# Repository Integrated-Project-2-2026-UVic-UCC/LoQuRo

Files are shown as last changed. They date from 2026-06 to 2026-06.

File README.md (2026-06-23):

<div align="center">
  
  <h1>LoQuRo</h1>
  <p><b>A fully custom-designed, AI-controlled quadrupedal robot built for under €300.</b><br>
  <i>Proof that autonomous legged locomotion doesn't require a six-figure budget.</i></p>

  
  
  
  
</div>

## Repository Structure

The architecture is cleanly separated into distinct, highly documented modules:

* **[Control & AI](https://github.com/Integrated-Project-2-2026-UVic-UCC/LoQuRo/tree/main/Software):** Sim-to-real pipelines, MuJoCo digital twins, PPO training scripts, and ROS 2 high-level nodes.
* **[Firmware](https://github.com/Integrated-Project-2-2026-UVic-UCC/LoQuRo/tree/main/Software):** The critical embedded layer. Highly optimized FreeRTOS multicore routines on ESP32-S3, Zenoh DDS bridging, and low-latency I²C sensor polling.
* **[Mechanics](https://github.com/Integrated-Project-2-2026-UVic-UCC/LoQuRo/tree/main/Mechanics):** PTC Creo CAD source files, STP assemblies, and URDF/MJCF simulation meshes.
* **[Electronics](https://github.com/Integrated-Project-2-2026-UVic-UCC/LoQuRo/tree/main/Electronics):** EasyEDA schematics, stackable PCB layouts, and comprehensive BOM.

**Quick Links:**
[Project Website](https://integrated-project-2-2026-uvic-ucc.github.io/LoQuRo/) | [Technical PDF](https://github.com/Integrated-Project-2-2026-UVic-UCC/LoQuRo/raw/main/docs/Technical_doc_IP2.pdf) | [GitHub Repository](https://github.com/Integrated-Project-2-2026-UVic-UCC/LoQuRo)

---

<div align="center">
  <video controls width="100%" style="max-width: 600px; border-radius: 8px; border: 1px solid rgba(255,255,255,0.1);">
    <source src="https://github.com/Integrated-Project-2-2026-UVic-UCC/LoQuRo/raw/main/docs/images/promotion.mp4" type="video/mp4">
  </video>
  <br>
  <a href="https://github.com/Integrated-Project-2-2026-UVic-UCC/LoQuRo/raw/main/docs/images/promotion.mp4">Watch promotional video</a>
</div>

---

## The Market Gap & Opportunity

> [!NOTE]
> **The Paradigm Shift:** Advanced quadrupedal platforms currently retail at €1,600–€3,000, operating as closed, black-box systems that limit R&D scalability. Low-cost DIY alternatives fail to provide the torque feedback and bandwidth required for modern AI deployment. LoQuRo bridges this gap with a highly optimized, open-architecture platform that drastically lowers the barrier to entry for reinforcement learning research and commercial deployment.

| Metric | Value | Strategic Advantage |
| --- | --- | --- |
| **BOM Cost** | `€278` | < 25% of entry-level commercial alternatives; highly scalable for fleets. |
| **DOF** | `12` | 3 per leg (full hip + knee articulation) enabling complex gait maneuvers. |
| **Weight** | `1.8 kg` | Exceptionally lightweight, reducing power consumption and material costs. |
| **Inertia** | `x13 Reduction` | Patented-style mechanical innovation maximizing commodity hardware efficiency. |

---

## Core Engineering Innovations

<details>
<summary><b>[01] Four-bar linkage leg mechanism</b></summary>
<br>
Rather than mounting the knee actuator directly at the joint, LoQuRo relocates it to the chassis via an aluminium four-bar transmission. This drastically reduces the rotational inertia of each leg by a factor of 13, enabling low-cost commodity servos to deliver dynamic performance margins usually reserved for expensive proprietary actuators.
<br><br>
<b>Repository link:</b> <a href="https://github.com/Integrated-Project-2-2026-UVic-UCC/LoQuRo/tree/main/Mechanics">View Mechanics R&D</a>
</details>

<details>
<summary><b>[02] GPU-parallelized PPO training</b></summary>
<br>
The locomotion policy was trained entirely in a digital twin using MuJoCo and mjlab, executing thousands of parallel environments simultaneously on GPU. The resulting ONNX model is highly efficient, running real-time inference on edge devices like a laptop or Raspberry Pi.
<br><br>
<div align="center">
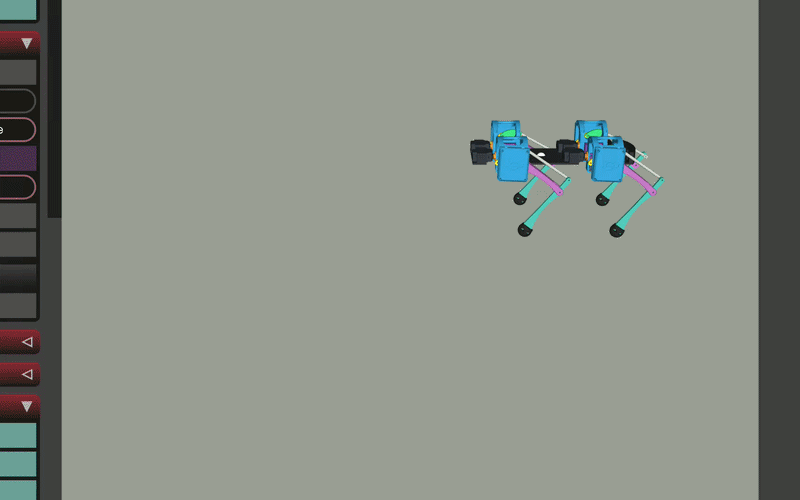
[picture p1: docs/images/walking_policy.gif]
LoQuRo Walking Policy Simulation
  
</div>
<br>
<b>Repository link:</b> <a href="https://github.com/Integrated-Project-2-2026-UVic-UCC/LoQuRo/tree/main/Software">View AI & Control Source</a>
</details>

<details>
<summary><b>[03] Advanced Embedded Firmware & Decentralized Control</b></summary>
<br>
A significant portion of the system's complexity resides in its firmware architecture. Bridging AI and hardware required writing highly optimized embedded C++ for the ESP32-S3. Leveraging FreeRTOS for deterministic multicore execution and Eclipse Zenoh (a lightweight data-centric middleware), the firmware achieves a blistering 7–9 ms WiFi latency. This ensures the 50 Hz real-time control loop remains perfectly synchronized for reactive locomotion.
<br><br>
<b>Repository link:</b> <a href="https://github.com/Integrated-Project-2-2026-UVic-UCC/LoQuRo/tree/main/Software">View Firmware Source</a>
</details>

<details>
<summary><b>[04] Custom dual-PCB architecture</b></summary>
<br>
Two purpose-designed, stackable PCBs handle per-leg power distribution, high-speed I²C multiplexing across 12 magnetic encoders, and IMU sensor fusion. By integrating everything at the board level, we eliminated wiring complexity, mitigated failure points, and paved the way for mass-manufacturing scalability.
<br><br>
<b>Repository link:</b> <a href="https://github.com/Integrated-Project-2-2026-UVic-UCC/LoQuRo/tree/main/Electronics">View Electronics & PCB Design</a>
</details>

---

## Development Outcomes & Viability

The core architecture is proven. The sim-to-real pipeline successfully transfers digital training to physical hardware.

* **[ 100% ] Stable walking policy trained in simulation**
PPO agent successfully learned forward, backward, and rotational gait patterns. Policy converged efficiently and exported to ONNX for edge deployment.
* **[ 100% ] Full-stack hardware & firmware integration**
The complex interplay between the embedded ESP32 firmware, custom PCBs, ROS 2 inference node, and Zenoh link was validated end-to-end with zero bottlenecks.
* **[ 85% ] Autonomous locomotion under strict budget**
Physical walking was achieved during outdoor testing. A transient current spike exceeded the XL4015 buck converters' limits, resulting in a servo failure. The root cause is fully diagnosed and serves as a vital stress-test data point.
* **[ Next Phase ] Iteration 2 for Commercial Readiness**
Transitioning from prototype to robust product. Planned upgrades include XL4016 modules, a 4-layer PCB with dedicated power planes for electrical resilience, and optimized structural geometry.

> [!WARNING]
> **Investment Context:** The hardware interruption during extreme load testing is a known boundary condition of the €300 constraint, not a fundamental design flaw. The control logic, firmware, and mechanical IP are completely sound. An allocation of just €150 in targeted component upgrades permanently resolves this bottleneck for version 2.0.

---

*LQR · LoQuRo · Lowcost Quadruped Robot · Scalable Mechatronics · UVic–UCC · June 2026*

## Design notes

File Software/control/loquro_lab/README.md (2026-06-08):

# loquro_lab

UV Python package containing the MuJoCo/mjlab RL environment and inference tooling for the **LoQuRo** custom quadruped robot.

## Setup

```bash
uv sync
```

## Training

From this package directory, sync the environment and check that the LoQuRo task is registered:

```bash
uv sync
uv run list-envs
```

The task list should include `Mjlab-Velocity-Flat-LoQuRo`.

Launch a training run with 4096 parallel environments:

```bash
uv run train Mjlab-Velocity-Flat-LoQuRo --env.scene.num-envs 4096
```

To use TensorBoard instead of the default W&B logger:

```bash
uv run train Mjlab-Velocity-Flat-LoQuRo --env.scene.num-envs 4096 --agent.logger tensorboard
```

Trained checkpoints are saved under `logs/rsl_rl/quad_bot_velocity/<run-timestamp>/`. At the end of training the final policy is exported to ONNX. Copy the `.onnx` file to `models/` and give it a name:

```bash
cp logs/rsl_rl/quad_bot_velocity/<run>/final.onnx models/loco_v0.onnx
```

## Running a trained policy (`play.py`)

`play.py` opens an interactive MuJoCo viewer and runs the robot under a named ONNX policy in real time.

```bash
uv run play.py <model_name> [options]
```

`<model_name>` is the filename (without `.onnx`) of a model stored in the `models/` directory.

### Examples

```bash
# Run loco_v0 with the default forward command (vx=0.3 m/s)
uv run play.py loco_v0

# Custom velocity command
uv run play.py loco_v0 --vx 0.5 --vy 0.0 --omega 0.3

# Stand still and use keyboard to drive
uv run play.py loco_v0 --vx 0.0
```

### Options

| Flag | Default | Description |
|---|---|---|
| `--vx` | `0.3` | Forward velocity command (m/s) |
| `--vy` | `0.0` | Lateral velocity command (m/s) |
| `--omega` | `0.0` | Yaw rate command (rad/s) |

### Viewer keyboard controls

| Key | Action |
|-----|---|
| `↑` / `↓` | Increase / decrease forward velocity (vx) by 0.05 m/s |
| `←` / `→` | Increase / decrease yaw rate (omega) by 0.1 rad/s |
| `W` / `S` | Increase / decrease lateral velocity (vy) by 0.05 m/s |
| `Space` | Zero all commands (robot stands still) |
| `R` | Reset simulation to initial stance |

The terminal prints the current command and trunk height on every control step so you can monitor the policy without switching windows.

## Robot overview

- **Legs:** 4-bar linkage, 4 legs — FL / FR / RL / RR
- **Actuated joints:** 12 (shoulder, knee, femur per leg) — Feetech SCS20 servos (1.96 Nm)
- **Sensors used by policy:** IMU accelerometer + gyroscope, 12 joint encoders
- **Control frequency:** 50 Hz (physics at 500 Hz, decimation = 10)
- **Model file:** `loquro_lab/xmls/loquro.xml`

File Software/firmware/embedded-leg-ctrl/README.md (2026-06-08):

## First-Time Setup

When powering on the robot for the first time, it will create a Wi-Fi access point called **LoQuRo**.

1. Turn on the robot.
2. Using a phone, tablet, or computer, connect to the **LoQuRo** Wi-Fi network.
3. A captive portal should open automatically. If it does not, reconnect to the network and wait a few seconds.
4. Enter:

   * Your Wi-Fi SSID
   * Your Wi-Fi password
   * The IP address of the device running ROS2 (Raspberry Pi, laptop, PC, etc.)
5. Save the configuration.

The ESP32 will automatically reboot and connect to the configured network.

Once connected, the robot can be started normally.

---

## Robot Startup and IMU Calibration

Every time the robot is powered on, the IMU must complete its calibration process.

When the **green LED turns on**:

1. Place the robot on a stable surface.
2. Keep it completely still for approximately **5 seconds**.

   * Gyroscope calibration is performed during this period.
   * Accelerometer calibration is also completed during this period.
3. Afterward, slowly move the robot through as many orientations as possible:

   * Rotate it around all axes.
   * Point it in different directions.
   * Avoid sudden movements.

This process allows the magnetometer to calibrate correctly.

Once calibration is finished, the robot will automatically move to its initial pose.

> [!IMPORTANT] A device running the ROS2 bridge must be connected to the same Wi-Fi network as the robot. Without the bridge running, communication between ROS2 and the ESP32 will not be established.

---

## ROS2 Bridge

The bridge is the core communication component between ROS2 (Fast DDS) and the ESP32 (Zenoh-Pico).

Start the bridge before launching any control or visualization nodes:

```bash
zenoh-bridge-ros2dds
```

The bridge must remain running during robot operation.

### Checking the Robot IP

The bridge output can be used to verify that the robot is connected and to identify the IP address assigned by the network.

---

## IMU Orientation Estimation (Madgwick Filter)

The robot publishes raw IMU and magnetometer measurements. To obtain a filtered orientation estimate, run the Madgwick filter:

```bash
ros2 run imu_filter_madgwick imu_filter_madgwick_node --ros-args \
  -r imu/data_raw:=/imu/data_raw \
  -r imu/mag:=/imu/mag \
  -p use_mag:=true
```

In another terminal:

```bash
rviz2
```

Inside RViz:

1. Set the fixed frame to:

   * `imu_link`, or
   * `base_link`
2. Click:

   * Add
   * By Topic
   * Select `imu/data`

The filtered orientation should now be visible.

> [!NOTE] Future versions will integrate the Madgwick filter directly into the ROS2 launch file so that it starts automatically.

---

## Control

After the bridge and IMU pipeline are running, control nodes can be launched.

Depending on the application, you can:

* Run the teleoperation node and manually control the robot.
* Launch autonomous control nodes.
* Execute test scripts such as:

```bash
python3 LoQuRo_xxxx.py
```

Ensure the bridge is active before running any control software.

---

## Testing

### Joint Command Test (Python)

This script publishes a fixed joint configuration and can be used to verify that the communication pipeline is working correctly.

The robot should move to a standing pose if commands are received successfully.

```bash
python3 -c "
import rclpy
from rclpy.node import Node
from sensor_msgs.msg import JointState

class P(Node):
    def __init__(self):
        super().__init__('p')
        self.pub = self.create_publisher(JointState, '/joint_commands', 10)
        self.create_timer(0.02, self.cb)

    def cb(self):
        m = JointState()
        m.header.stamp = self.get_clock().now().to_msg()
        m.header.frame_id = 'base_link'
        m.name = ['lf_haa','lf_hfe','lf_kfe',
                  'rf_haa','rf_hfe','rf_kfe',
                  'lh_haa','lh_hfe','lh_kfe',
                  'rh_haa','rh_hfe','rh_kfe']
        m.position = [0.7, 0.8, 0.8] * 4
        self.pub.publish(m)

rclpy.init()
rclpy.spin(P())
"
```

---

## Debug and Development Utilities

The firmware includes several debugging utilities that can be enabled directly in the source code when diagnosing hardware, communication, or control issues.

These tools are intended for development and troubleshooting purposes only.

### Encoder Monitoring

Prints encoder measurements for all joints through the serial monitor.

Useful for:

- Verifying encoder communication.
- Checking measured joint angles.
- Diagnosing calibration issues.

```cpp
static unsigned long last_print = 0;
static float enc_debug[12] = {0};

if (millis() - last_print >= 100)
{
    last_print = millis();

    if (xQueuePeek(Queues::encoder_data_queue, &enc_debug, pdMS_TO_TICKS(200)) == pdTRUE)
    {
        Serial.println("\n--- [DEBUG] ENCODERS ---");

        const char *leg_names[4] = {"LF", "RF", "LH", "RH"};

        for (int leg = 0; leg < 4; leg++)
        {
            float haa = enc_debug[leg * 3 + 0];
            float hfe = enc_debug[leg * 3 + 1];
            float kfe = enc_debug[leg * 3 + 2];

            Serial.printf(
                "Leg %s: HAA=%.2f | HFE=%.2f | KFE=%.2f deg\n",
                leg_names[leg],
                haa,
                hfe,
                kfe);
        }
    }
}
```

### I2C Device Scanner

Scans both I2C buses and reports all detected devices.

Useful for:

- IMU troubleshooting.
- Encoder diagnostics.
- Hardware integration verification.

```cpp
byte error, address;
int nDevices;

nDevices = 0;
Serial.println("=== Scanning Wire (SDA=8, SCL=9) ===");

for (address = 1; address < 127; address++)
{
    Wire.beginTransmission(address);
    error = Wire.endTransmission();

    if (error == 0)
    {
        Serial.print("Device found at 0x");
        if (address < 16)
            Serial.print("0");
        Serial.println(address, HEX);
        nDevices++;
    }
}

Serial.printf("%d device(s) found.\n", nDevices);

nDevices = 0;
Serial.println("=== Scanning Wire1 (SDA=17, SCL=18) ===");

for (address = 1; address < 127; address++)
{
    Wire1.beginTransmission(address);
    error = Wire1.endTransmission();

    if (error == 0)
    {
        Serial.print("Device found at 0x");
        if (address < 16)
            Serial.print("0");
        Serial.println(address, HEX);
        nDevices++;
    }
}

Serial.printf("%d device(s) found.\n", nDevices);
```

### Joint State Monitoring

Prints the internal joint states processed by the controller.

Useful for:

- Verifying ROS command reception.
- Debugging kinematic calculations.
- Checking state estimation.

```cpp
static unsigned long last_print = 0;

if (millis() - last_print >= 1000)
{
    memcpy(joint_states_debug, &joint_states, 4 * 3 * sizeof(float));
    last_print = millis();

    Serial.println("\n--- [DEBUG] ROBOT STATE ---");

    for (int leg = 0; leg < 4; leg++)
    {
        Serial.printf(
            "Leg %d: HAA=%.4f | HFE=%.4f | KFE=%.4f rad\n",
            leg,
            joint_states_debug[leg][0],
            joint_states_debug[leg][1],
            joint_states_debug[leg][2]);
    }
}
```

### Servo Disable Mode

Disables all leg motion while keeping the rest of the firmware running.

Useful for:

- Sensor debugging.
- Communication testing.
- Safe development.

```cpp
leg_lf.write(0.0, 0.0, 0.0);
leg_rf.write(0.0, 0.0, 0.0);
leg_lh.write(0.0, 0.0, 0.0);
leg_rh.write(0.0, 0.0, 0.0);
```

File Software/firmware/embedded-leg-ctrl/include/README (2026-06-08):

# Include Directory

This directory contains the project header files for the ESP32 quadruped robot firmware.

A header file contains C/C++ declarations and macro definitions shared between several source files. You request the use of a header file in your source file by including it with the C preprocessing directive `#include`.

```cpp
// src/main.cpp

#include "config.h"
#include "hardware.h"

void setup() { ... }
void loop() { ... }
```

Including a header file produces the same results as copying its contents into each source file that needs it. With header files, related declarations appear in only one place — if they need to be changed, they can be changed once, and every file that includes them will use the new version on the next recompile.

---

## Header Files

### `config.h`
Global project configuration. Defines WiFi, Zenoh session mode, and all ROS topic key expressions (`joint_commands`, `joint_states`, `imu/data_raw`, `imu/mag`). Also includes the core Arduino and networking libraries (`WiFi.h`, `WiFiManager.h`, `Preferences.h`, `Wire.h`).

### `hardware.h`
Hardware abstraction layer. Defines the `Leg` struct, which groups three `PCA9685Servo` joints (HAA, HFE, KFE) per leg, and the `ServoParams` namespace with the PCA9685 channel assignments for all twelve joints across the four legs. Declares the global `pwm` driver, the four `Leg` instances, the `joint_states` matrix, and the `IMUMPU9250` IMU object.

### `PCA9685.h`
Servo driver wrapper around `Adafruit_PWMServoDriver`. The `PCA9685Servo` class handles conversion from radians (or degrees) to PWM ticks at 100 Hz, with configurable per-joint travel limits. The `PCA9685Cfg` namespace holds the timing constants (`min_us`, `max_us`, `period_us`, `ticks_per_us`).

### `IMUMPU9250.h`
IMU driver for the MPU-9250. Exposes `measure` (x/y/z float triplet) and `IMUdata` (accel, gyro, mag) structs. The `IMUMPU9250` class provides `begin()`, `calibrate()`, `calibrateMag()`, and individual `getAccel()` / `getGyro()` / `getMag()` methods. Calibration constants are in the `IMUCfg` namespace.

### `mailbox.h`
FreeRTOS inter-task communication interface. Declares the `Queues` namespace with the four `QueueHandle_t` objects used to pass data between tasks: `joint_states_queue`, `time_stamp_queue`, `encoder_data_queue`, and `imu_data_queue`.

### `tasks.h`
Declarations for all FreeRTOS tasks and the Zenoh data handler callback: `readEncodersTask`, `readIMUTask`, `writeServosTask`, `sendStatusTask`, `watchdogTask`, and `data_handler`.

### `utilities.h`
Helper functions for serialization, deserialization, and networking. Includes `deserializeJointStates()`, `serializeImu()`, `serializeMag()`, `serializeJointStates()`, `getPreciseTime()`, and `beginNetwork()`. Uses `ucdr/microcdr.h` for CDR-based ROS 2 message encoding.

### `zenoh.h`
Zenoh-pico session interface. Declares the global session object (`z_owned_session_t`), the joint-states subscriber (`z_owned_subscriber_t`), and the three publishers for IMU, magnetometer, and encoder data.

### `ServoCtrl.h`
Legacy servo driver using the ESP32 LEDC peripheral directly via GPIO pins. Superseded by `PCA9685.h` but kept for reference. The `ServoCtrl` class and `ServoCfg` namespace mirror the PCA9685 interface at 50 Hz.

---

## Dependency Graph

```
config.h
└── (WiFi, WiFiManager, Preferences, Wire, Arduino)

hardware.h
├── PCA9685.h
│   └── Adafruit_PWMServoDriver
└── IMUMPU9250.h
    └── config.h

mailbox.h
└── FreeRTOS (queue.h)

tasks.h
└── zenoh.h
    └── zenoh-pico

utilities.h
├── ucdr/microcdr.h
└── IMUMPU9250.h
```

---

For more on header files see the official GCC documentation:
https://gcc.gnu.org/onlinedocs/cpp/Header-Files.html

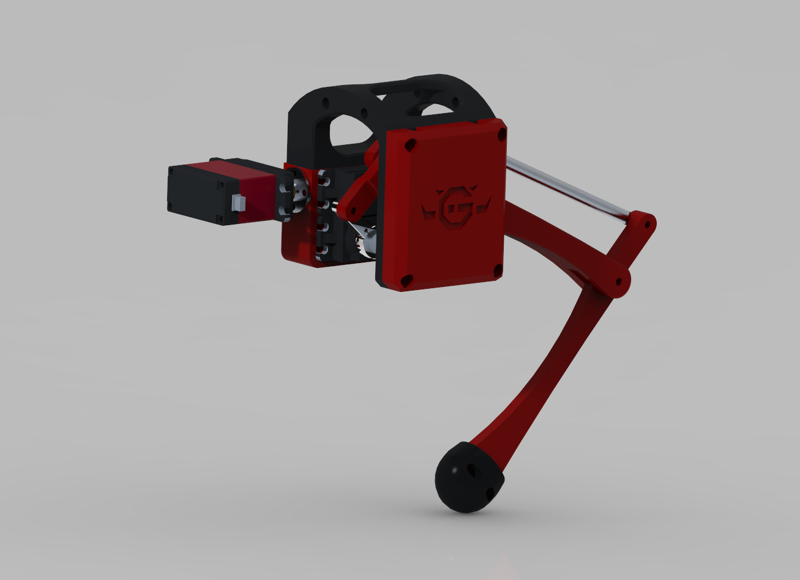
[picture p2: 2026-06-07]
Mechanics/encoder_render.png

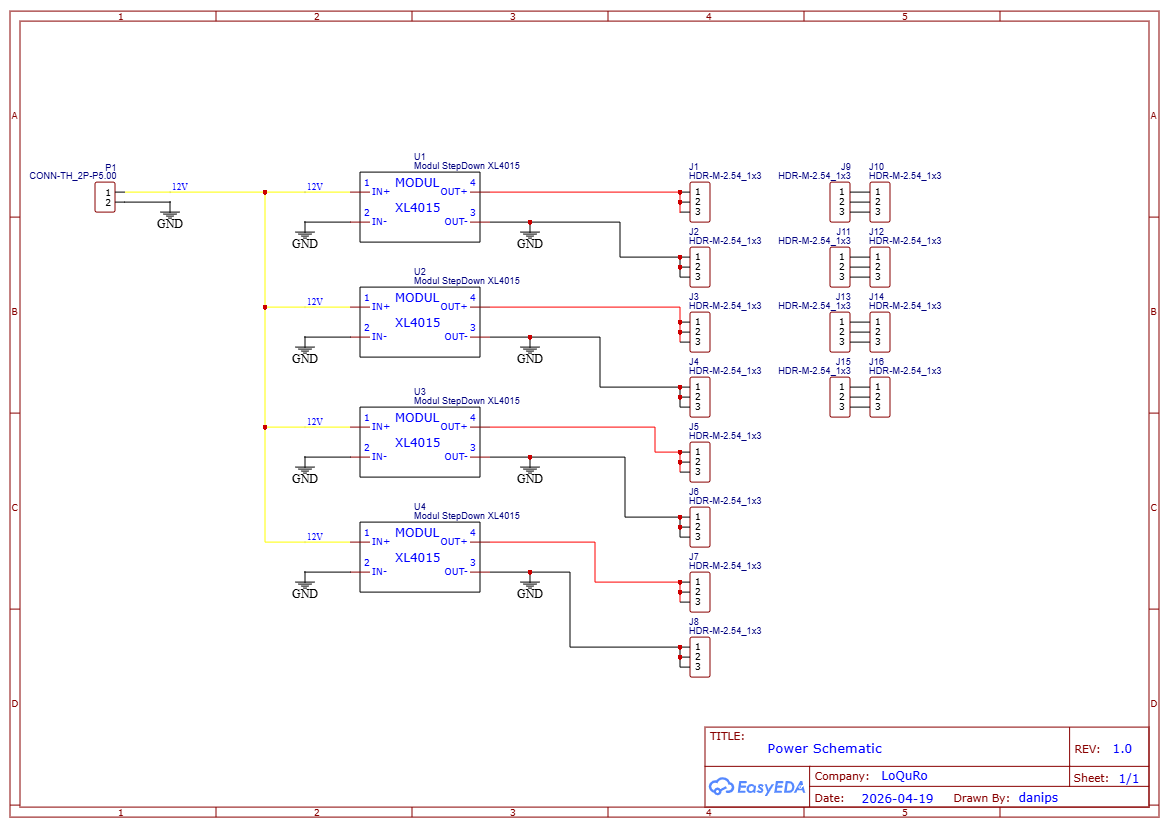
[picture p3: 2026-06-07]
Electronics/Schematic_PCB-Potencia-Reinforcement-Learning-Dog_2026-06-05.png

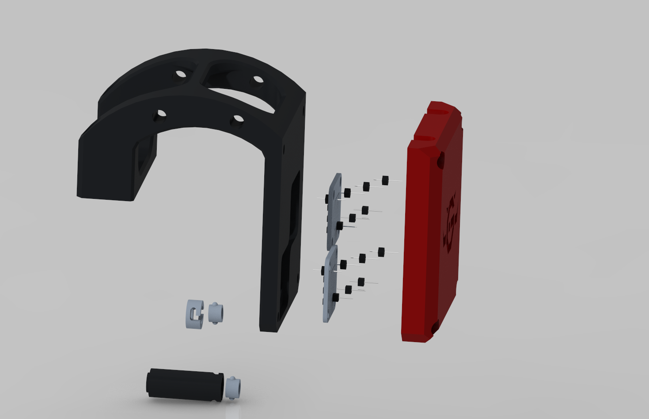
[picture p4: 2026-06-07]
Mechanics/encoder_system.png

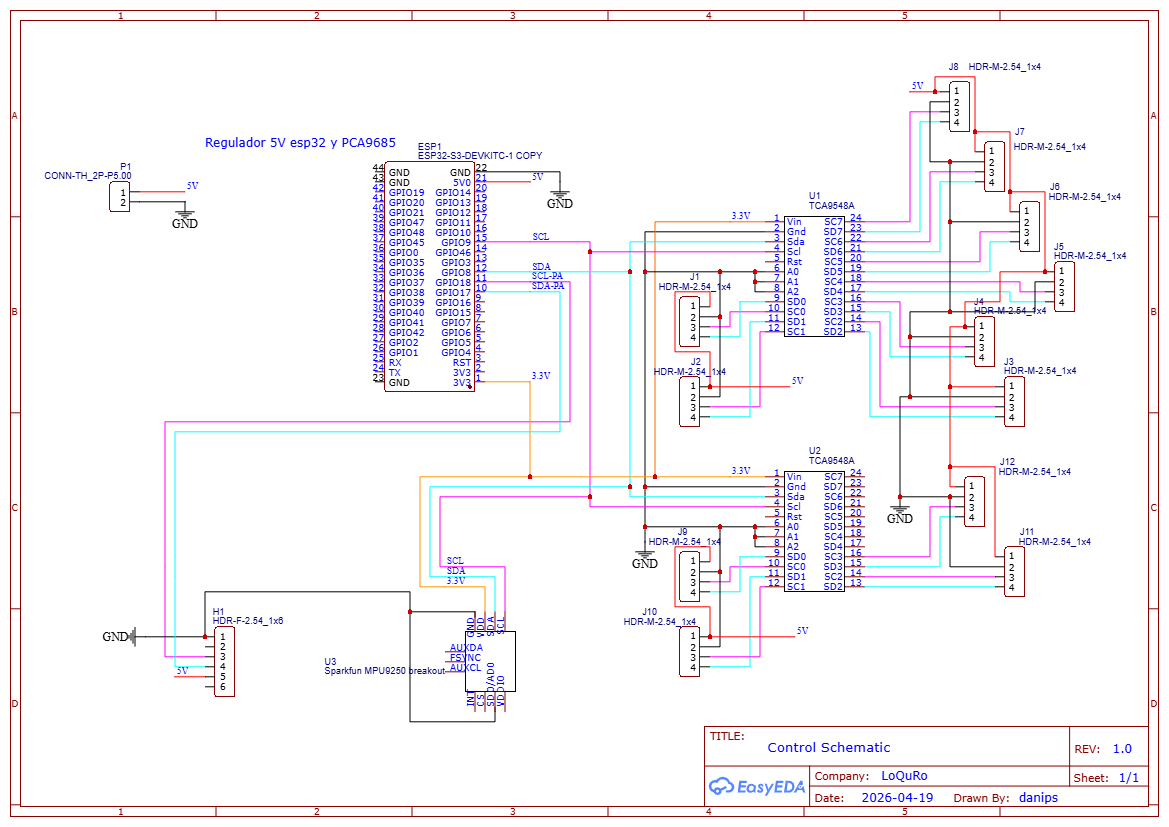
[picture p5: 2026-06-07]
Electronics/Schematic_Control-PCB-Reinforcement-Learning-Dog_2026-06-07.png

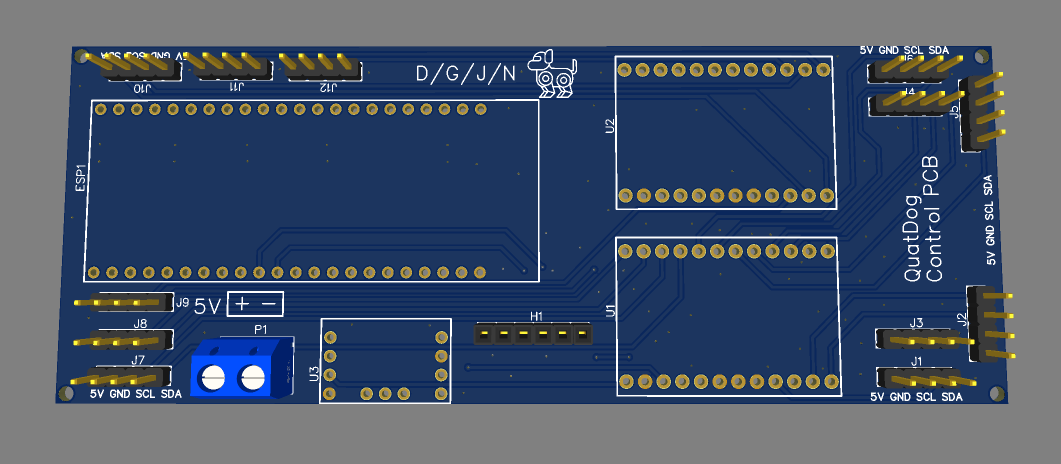
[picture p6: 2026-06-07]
Electronics/Render3D_Control_PCB.png

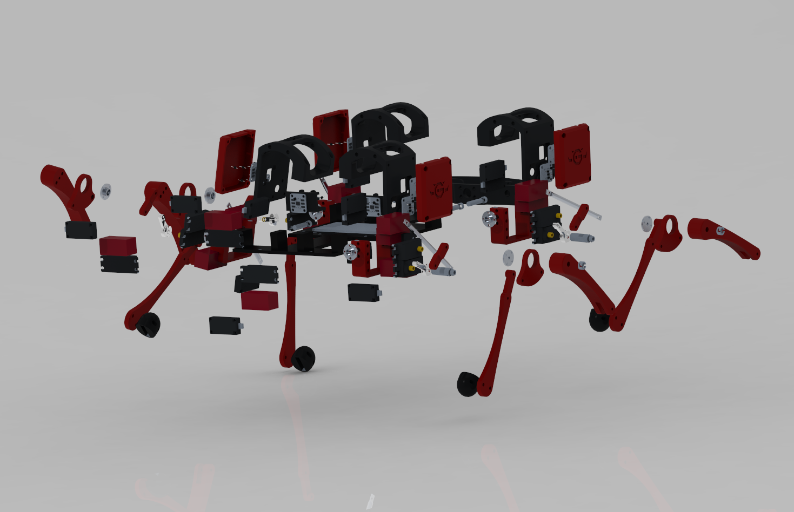
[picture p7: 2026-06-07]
Mechanics/exploded_view.png

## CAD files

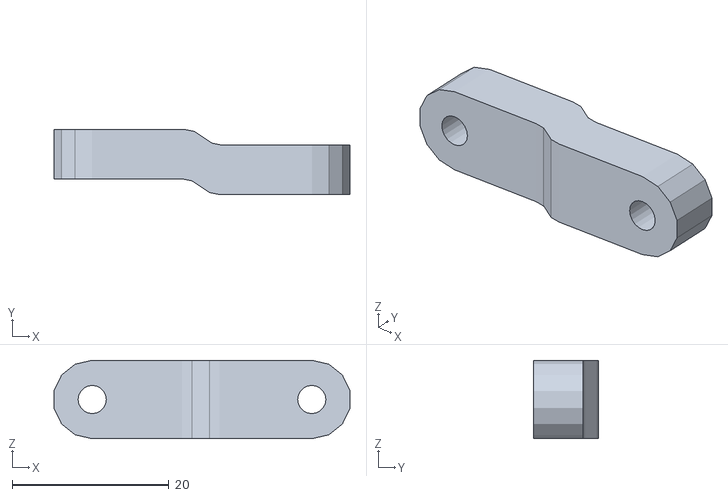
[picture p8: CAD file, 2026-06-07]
Mechanics/pieza1_pierna_left_mir.stl
37.7 x 8.30 x 10.0

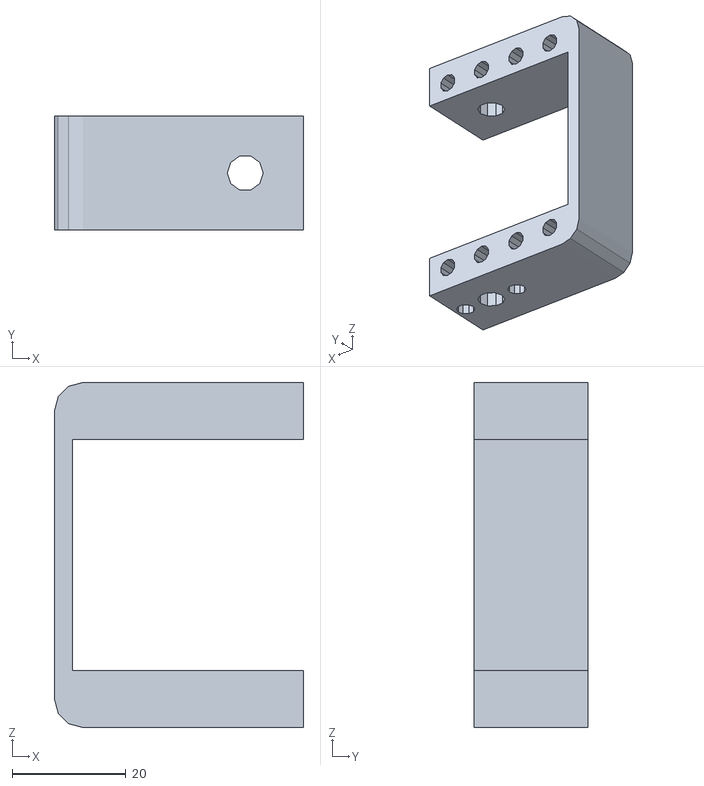
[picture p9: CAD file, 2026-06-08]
Software/control/loquro_lab/loquro_lab/xmls/assets/hombro_pierna_correct.stl
43.8 x 20.0 x 60.6

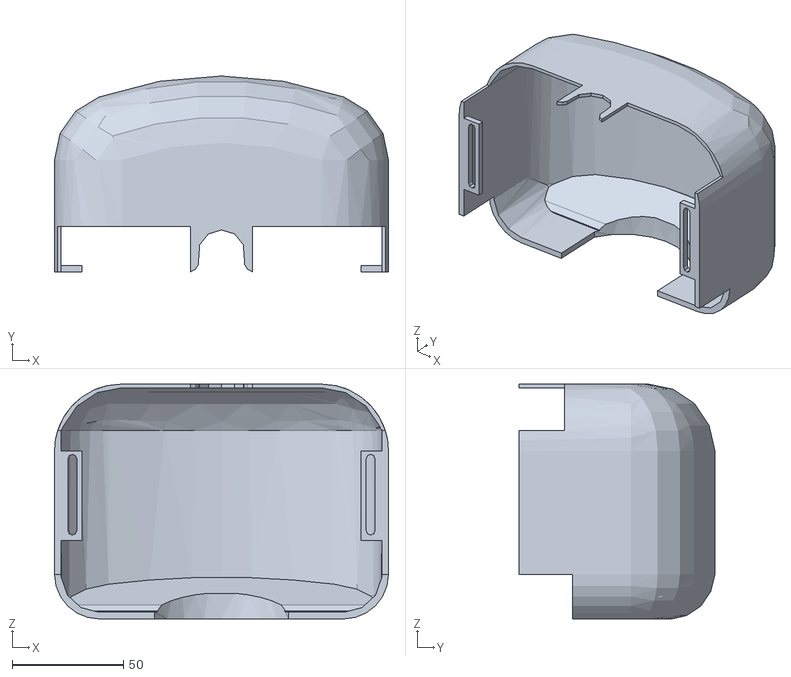
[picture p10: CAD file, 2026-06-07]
Mechanics/carcasa_final.stl
150.0 x 88.0 x 105.5

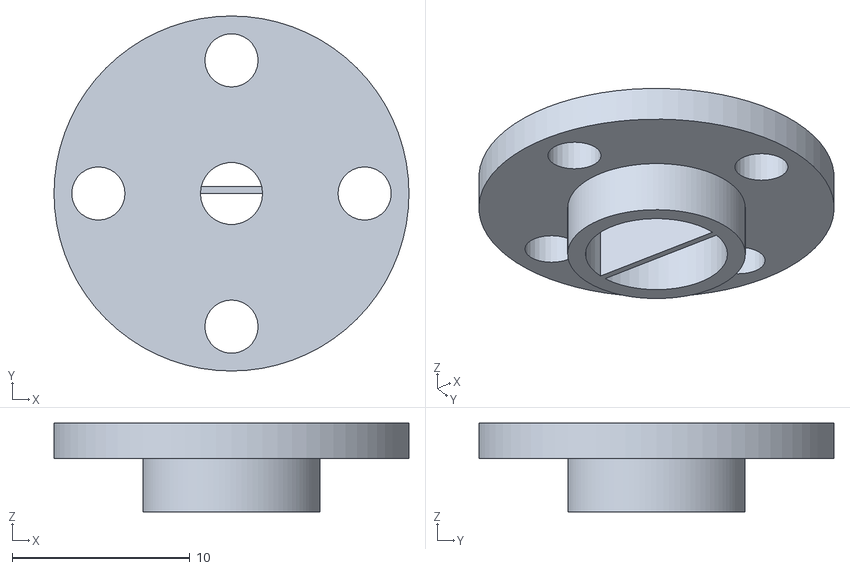
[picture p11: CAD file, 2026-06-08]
Software/control/loquro_lab/loquro_lab/xmls/assets/union_servo_correct.stl
20.0 x 20.0 x 5.00

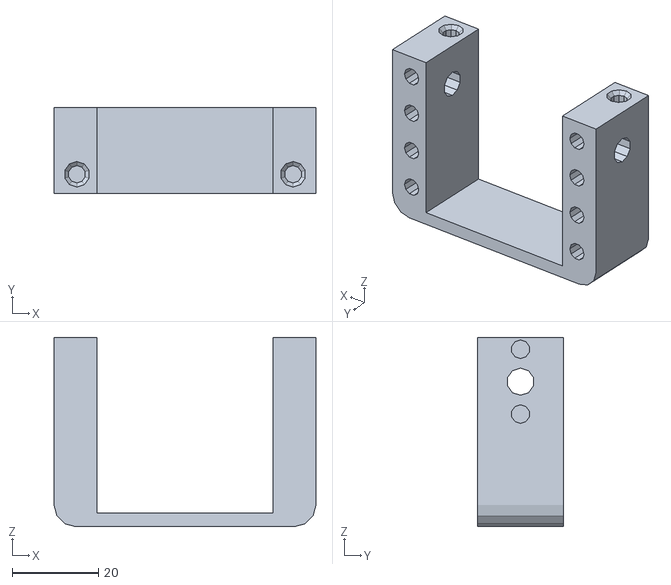
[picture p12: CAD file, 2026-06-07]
Mechanics/hombro_pierna.stl
60.6 x 20.0 x 43.8

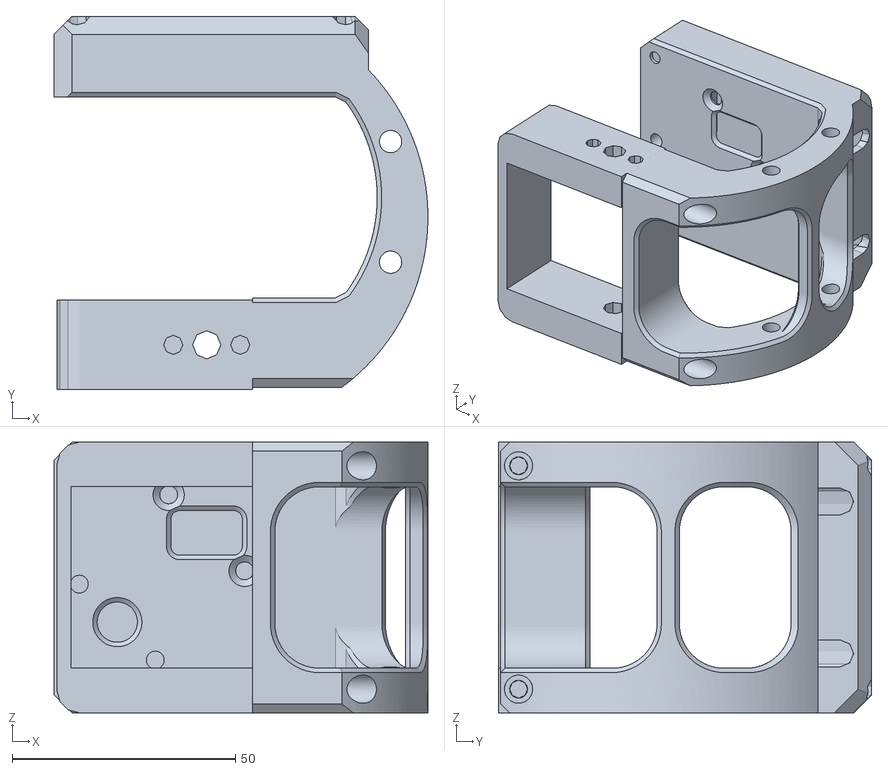
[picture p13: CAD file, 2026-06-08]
Software/control/loquro_lab/loquro_lab/xmls/assets/hombro_pierna_correct_r_encoders.stl
83.7 x 83.5 x 60.6

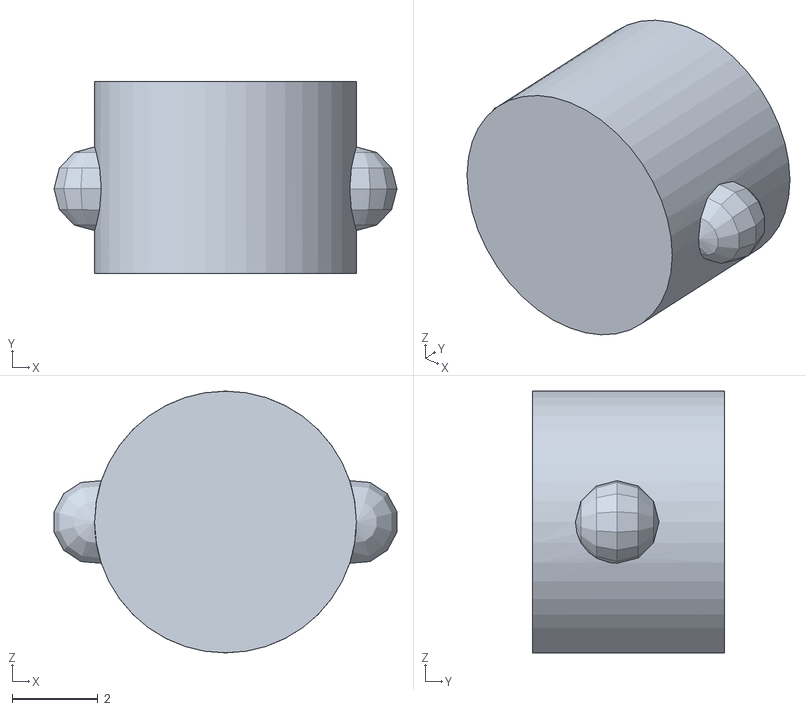
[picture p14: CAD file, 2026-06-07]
Mechanics/sujetador_iman_femur.stl
7.99 x 4.47 x 6.10

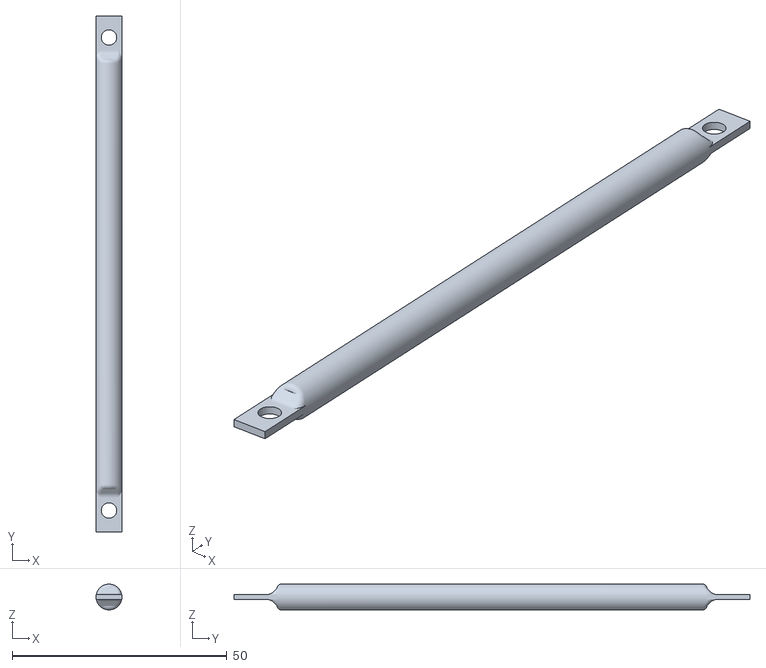
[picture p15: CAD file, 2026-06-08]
Software/control/loquro_lab/loquro_lab/xmls/assets/tensor_aluminio_110_60.stl
6.00 x 120.0 x 6.00

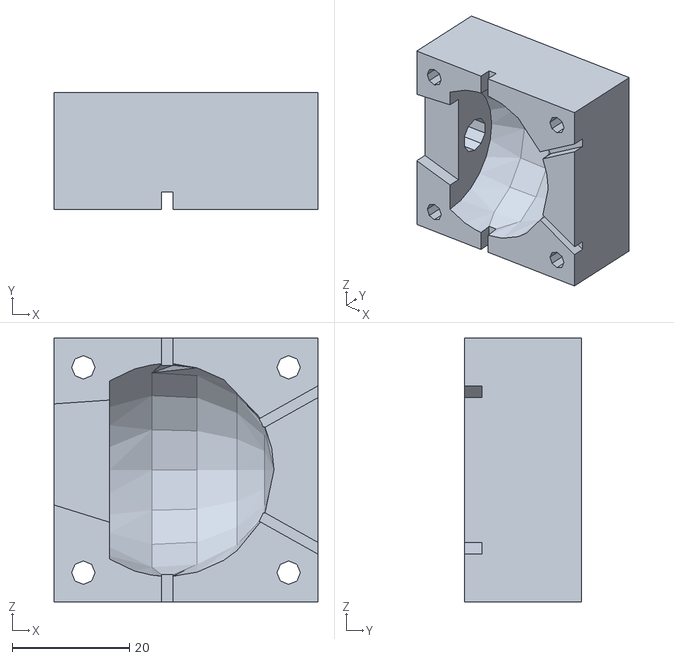
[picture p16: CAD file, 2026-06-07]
Mechanics/molde_esfera_p1.stl
45.0 x 20.0 x 45.0

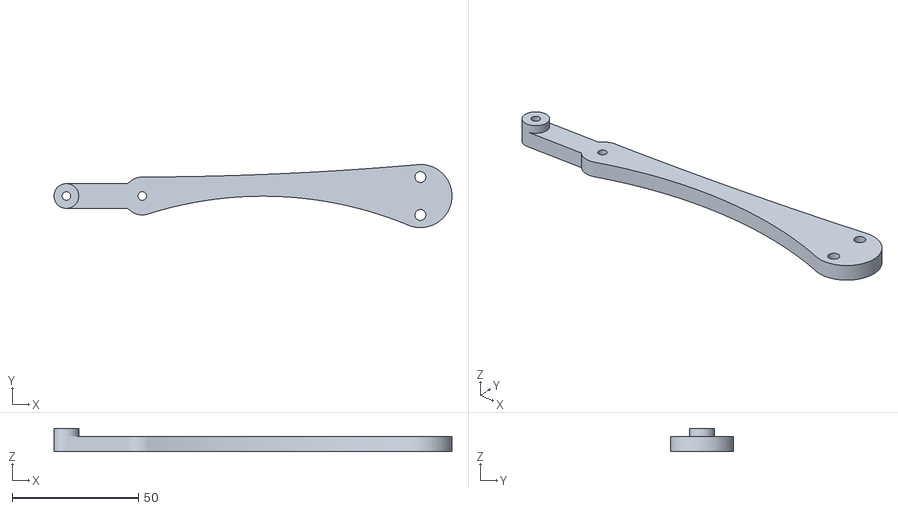
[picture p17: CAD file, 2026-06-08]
Software/control/loquro_lab/loquro_lab/xmls/assets/pieza4_pierna_right_correct.stl
157.4 x 25.0 x 9.15

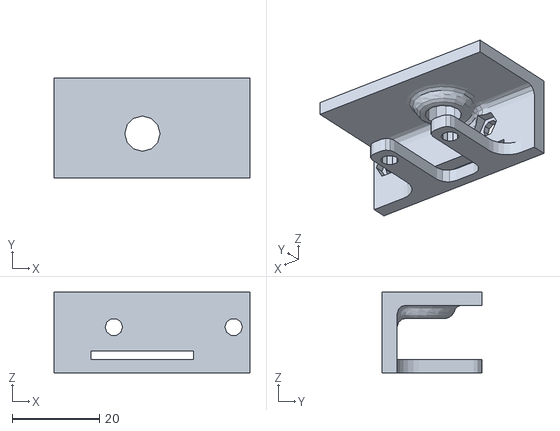
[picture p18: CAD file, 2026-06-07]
Mechanics/pared_cojinete_mir.stl
45.0 x 23.0 x 18.5

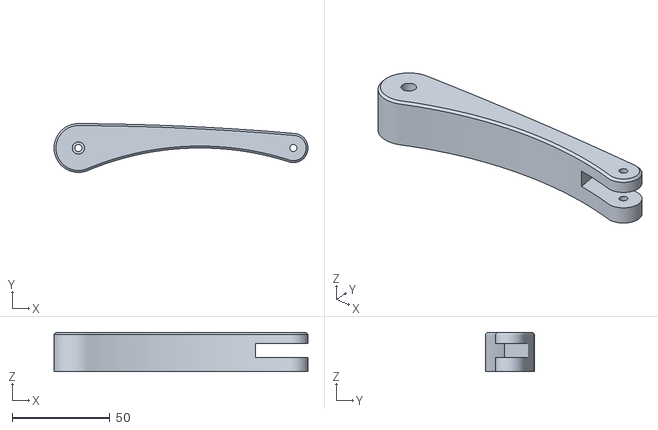
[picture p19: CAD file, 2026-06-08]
Software/control/loquro_lab/loquro_lab/xmls/assets/pieza3_pierna_felt_correct.stl
130.0 x 25.0 x 20.0

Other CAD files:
Mechanics/pieza1_pierna_left.stl
Software/control/loquro_lab/loquro_lab/xmls/assets/pieza1_pierna_right_correct.stl
Software/control/loquro_lab/loquro_lab/xmls/assets/tensor_aluminio_11_60_correct.stl
Mechanics/hombrera_encoders.stl
Mechanics/hombro_pierna_mir.stl
Software/control/loquro_lab/loquro_lab/xmls/assets/pieza1_pierna_left_correct.stl
Mechanics/base_dog.stl
Mechanics/iman_femur.stl
Mechanics/iman_tibia.stl
Mechanics/imanes_ejes_base.stl
Mechanics/molde_esfera_p2.stl
Mechanics/pared_cojinete.stl
Mechanics/parte_trasera_encoders.stl
Mechanics/pieza2_pierna_left.stl
Mechanics/pieza2_pierna_left_mir.stl
Mechanics/pieza3_pierna_left.stl
Mechanics/pieza3_pierna_left_mir.stl
Mechanics/pieza4_pierna_left.stl
Mechanics/pieza4_pierna_left_mir.stl
Mechanics/protector_encoders.stl
Mechanics/sujetador_iman_tibia.stl
Software/control/loquro_lab/loquro_lab/xmls/assets/base_dog.stl
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

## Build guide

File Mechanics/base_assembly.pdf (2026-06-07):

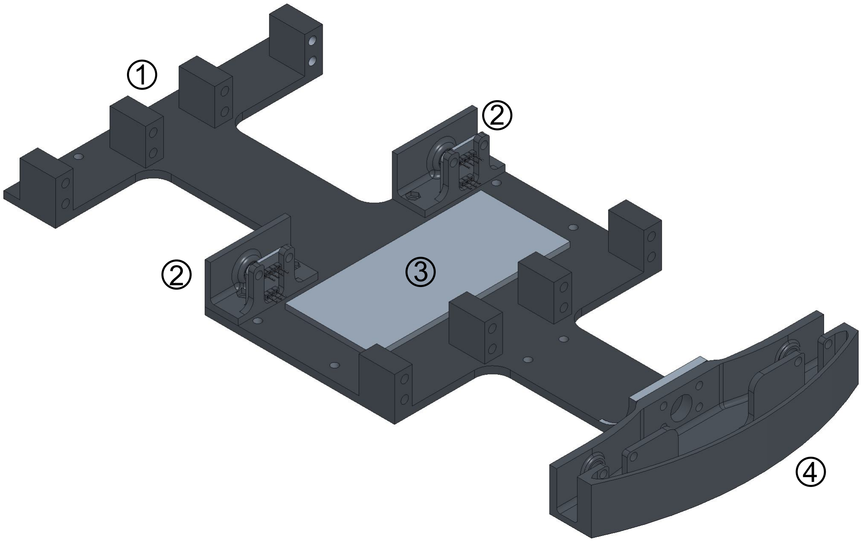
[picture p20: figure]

Item | Description 1 | Base 2 | Support Encoders 3 | Electronic Zone 4 | Back Zone

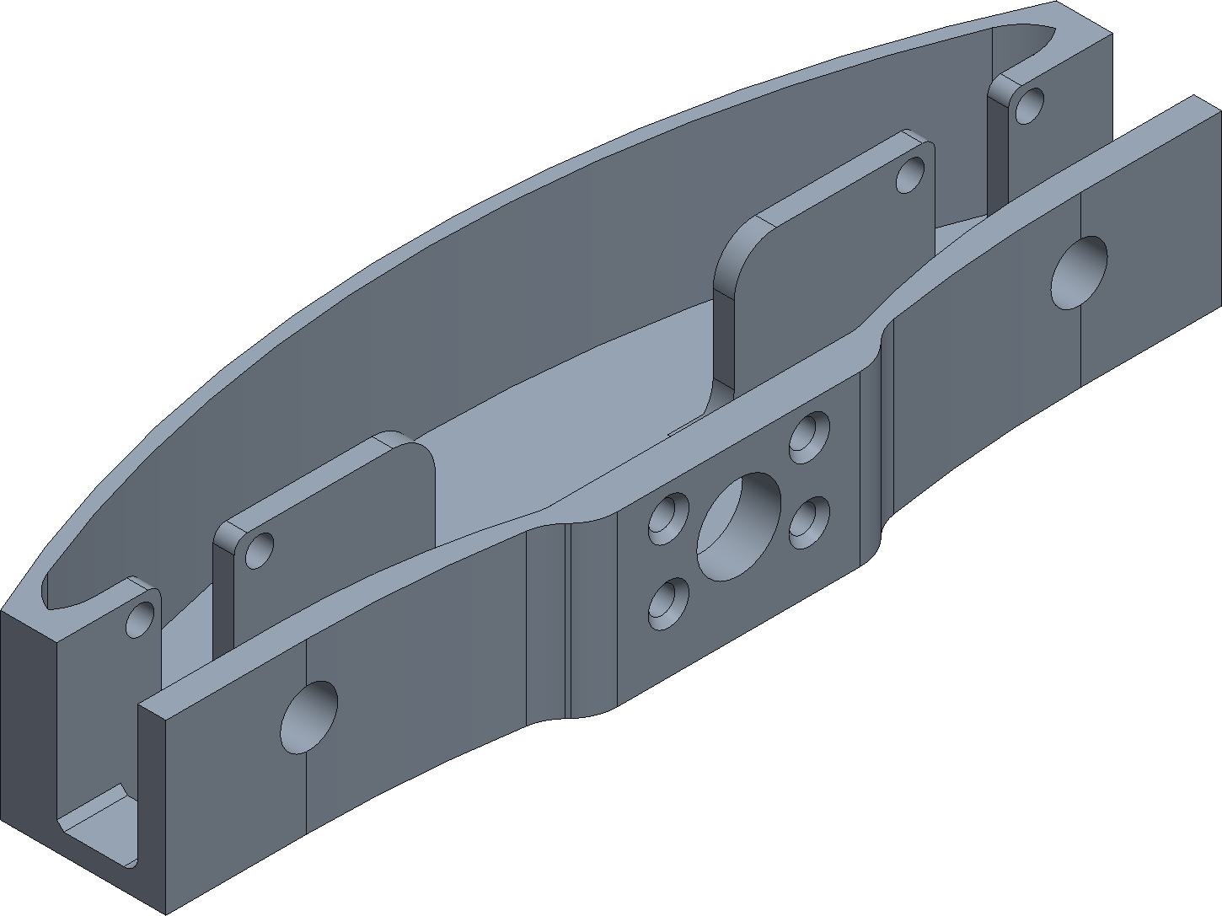
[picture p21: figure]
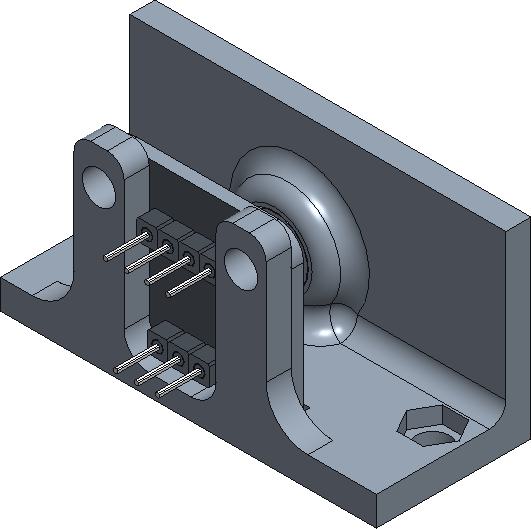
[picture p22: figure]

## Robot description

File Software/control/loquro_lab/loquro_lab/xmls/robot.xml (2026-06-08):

<mujoco model="loquro_quadruped">
  <compiler angle="radian" meshdir="assets/"/>

  <option timestep="0.0005" integrator="implicitfast" iterations="80" ls_iterations="30" gravity="0 0 -9.81"/>

  <default>
    <default class="visual">
        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
    </default>

    <default class="collision">
        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
    </default>
  </default>

  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

  <worldbody>
    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
    <light pos="0 0 5" dir="0 0 -1"/>
    
    <body name="trunk" pos="0 0 0.1" euler=" 0 0 0">
      <freejoint name="root"/>
      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
      <body name="fl_mount" pos="0.108 0.055 0.01" euler="0 0 3.14159">
        <body name="fl_shoulder_servo" pos="0 0 0" quat="0.000563312 0.707388 0.000562864 0.706825">
          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
          <body name="fl_servo_u_1" pos="0 0 0.005" euler="0 0 -0.7023">
            <joint name="fl_shoulder_joint" pos="0 0 0" axis="0 0 1" range="-0.8685 2.2731" armature="0.004" damping="0.12" frictionloss="0.003"/>
            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
            <body name="fl_hombro_pierna" pos="0 0 0.002">
              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
              <body name="fl_knee_servo" pos="-0.02 0.023 0.02" quat="0.707388 -0.706825 0 0">
                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
                <body name="fl_servo_u_2" pos="0 0 0.005" euler="0 0 -4.610055">
                  <joint name="fl_knee_joint" pos="0 0 0" axis="0 0 1" range="-1.57 1.57" armature="0.004" damping="0.12" frictionloss="0.003"/>
                  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
                  <body name="fl_pieza1_pierna" pos="-0.022 -0.042 0.001" euler="0 0 3.813813">
                    <joint name="fl_pieza1_pierna_joint" pos="-0.028 0 0" axis="0 0 1" range="-1.5708 1.5708" damping="0.03" frictionloss="0.0002"/>
                    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
                  </body>
                </body>
              </body>
              <body name="fl_hip_servo" pos="0 0.023 0.04" quat="9.38559e-07 -9.37812e-07 0.706825 0.707388">
                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
                <body name="fl_homoplato" euler="0 0 0.881112">
                  <joint name="fl_shoulder_passive_joint" pos="0 0 0" axis="0 0 1" range="-1.5708 1.5708" damping="0.03" frictionloss="0.0002"/>
                  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
                  <body name="fl_tensor_aluminio" pos="0.0213 0.0211 0.0067" euler="0 0 -2.289192">
                    <joint name="fl_tensor_aluminio_passive_joint" pos="0 0 0" axis="0 0 1" range="-1.5708 1.5708" damping="0.03" frictionloss="0.0002"/>
                    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
                  </body>
                </body>
                <body name="fl_femur" pos="0 0 0.006" euler="0 0 0.1574">
                  <joint name="fl_femur_joint" pos="0 0 0" axis="0 0 1" range="-1.7282 1.4134" damping="0.03" frictionloss="0.0002"/>
                  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
                  <body name="fl_tibia" pos="0.11 0 0.0076" euler="3.14159 0 1.586181">
                    <joint name="fl_tibia_passive_joint" pos="0 0 0" axis="0 0 1" range="-1.5708 1.5708" damping="0.03" frictionloss="0.0002"/>
                    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
                  </body>
                </body>
              </body>
            </body>
          </body>
        </body>
      </body>

      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
      <body name="fr_mount" pos="0.108 -0.055 0.01" euler="0 0 3.14159">
        <body name="fr_shoulder_servo" pos="0 0 0" euler="0 1.5708 0">
          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
          <body name="fr_servo_u_1" pos="0 0 0.005" euler="0 0 2.434">
            <joint name="fr_shoulder_joint" pos="0 0 0" axis="0 0 1" range="-1.5708 1.5708" armature="0.004" damping="0.12" frictionloss="0.003"/>
            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
            <body name="fr_hombro_pierna" pos="0 0 0.002" euler="0 3.14159 3.14159">
              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
              <body name="fr_knee_servo" pos="-0.0200215 0.0230215 -0.0200215" euler="-1.571 0 3.14159">
                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
                <body name="fr_servo_u_2" pos="0 0 0.005" euler="0 0 3.13">
                  <joint name="fr_knee_joint" pos="0 0 0" axis="0 0 1" range="0 1.57" armature="0.004" damping="0.12" frictionloss="0.003"/>
                  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
                  <body name="fr_pieza1_pierna" pos="0.00 -0.02451 0.0093" euler="0 0 3.993">
                    <joint name="fr_pieza1_pierna_joint" pos="0 0 0" axis="0 0 1" range="-1.5708 1.5708" damping="0.03" frictionloss="0.0002"/> 
                    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
                  </body>
                </body>
              </body>
              <body name="fr_hip_servo" pos="0 0.0230215 -0.04055" euler="-1.571 0 0">
                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
                <body name="fr_homoplato" pos="0 0 0" euler="3.14159 0 -0.729">
                  <joint name="fr_shoulder_passive_joint" pos="0 0 0" axis="0 0 1" range="-1.5708 1.5708" damping="0.03" frictionloss="0.0002"/>
                  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 
                  <body name="fr_tensor_aluminio" pos="0.02125 0.02108 -0.006" euler=" 0 0 -2.155">
                    <joint name="fr_tensor_aluminio_passive_joint" pos="0 0 0" axis="0 0 1" range="-1.5708 1.5708" damping="0.03" frictionloss="0.0002"/>
                    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
                  </body>
                </body>
                <body name="fr_femur" pos="0 0 0.006" euler="3.14159 0 -1.306">
                  <joint name="fr_femur_joint" pos="0 0 0" axis="0 0 -1" range="-1.5708 1.5708" damping="0.03" frictionloss="0.0002"/>
                  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
                  <body name="fr_tibia" pos="0.11 0 -0.0077" euler="3.14159 0 -4.5936">
                    <joint name="fr_tibia_passive_joint" pos="0 0 0" axis="0 0 1" range="-1.5708 1.5708" damping="0.03" frictionloss="0.0002"/>
                    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
                  </body>
                </body>
              </body>
            </body>
          </body>
        </body>
      </body>
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

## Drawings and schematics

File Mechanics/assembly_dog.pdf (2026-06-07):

○

○○

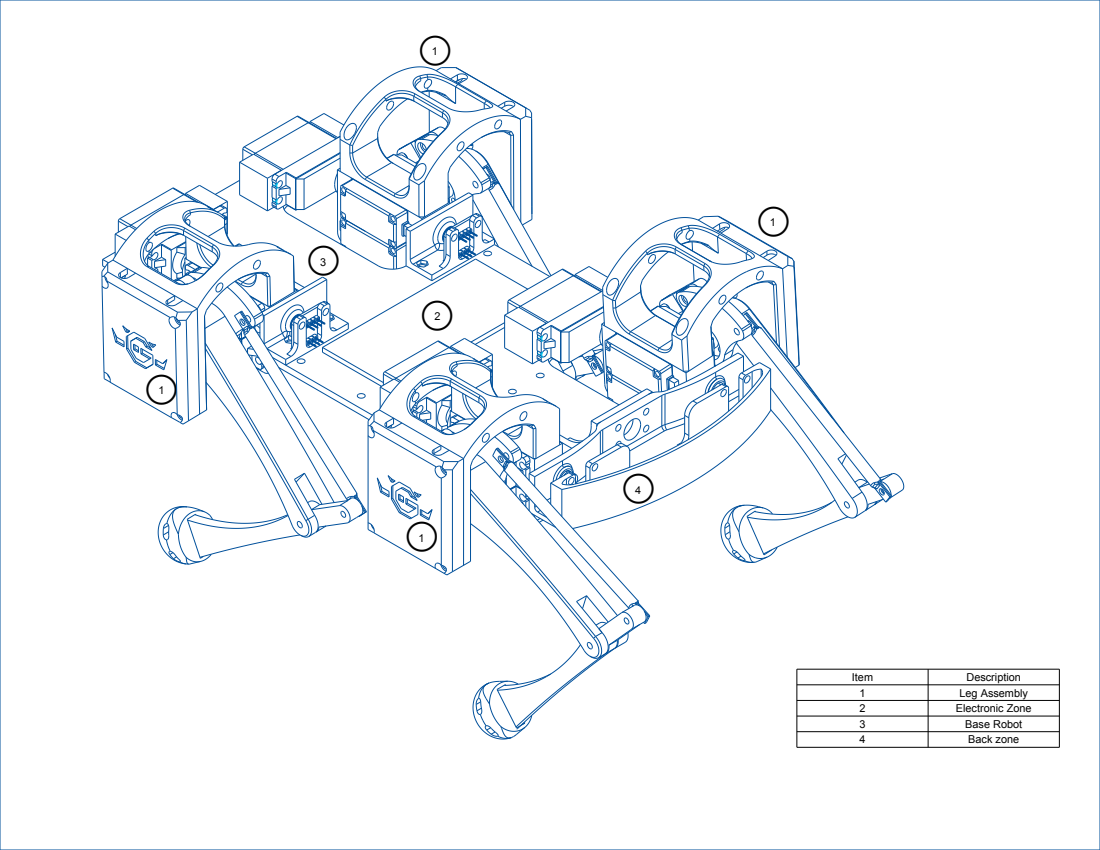
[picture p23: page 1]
Item; Description 1; Leg Assembly 2; Electronic Zone 3; Base Robot 4; Back zone

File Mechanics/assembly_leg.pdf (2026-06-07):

- ○
○

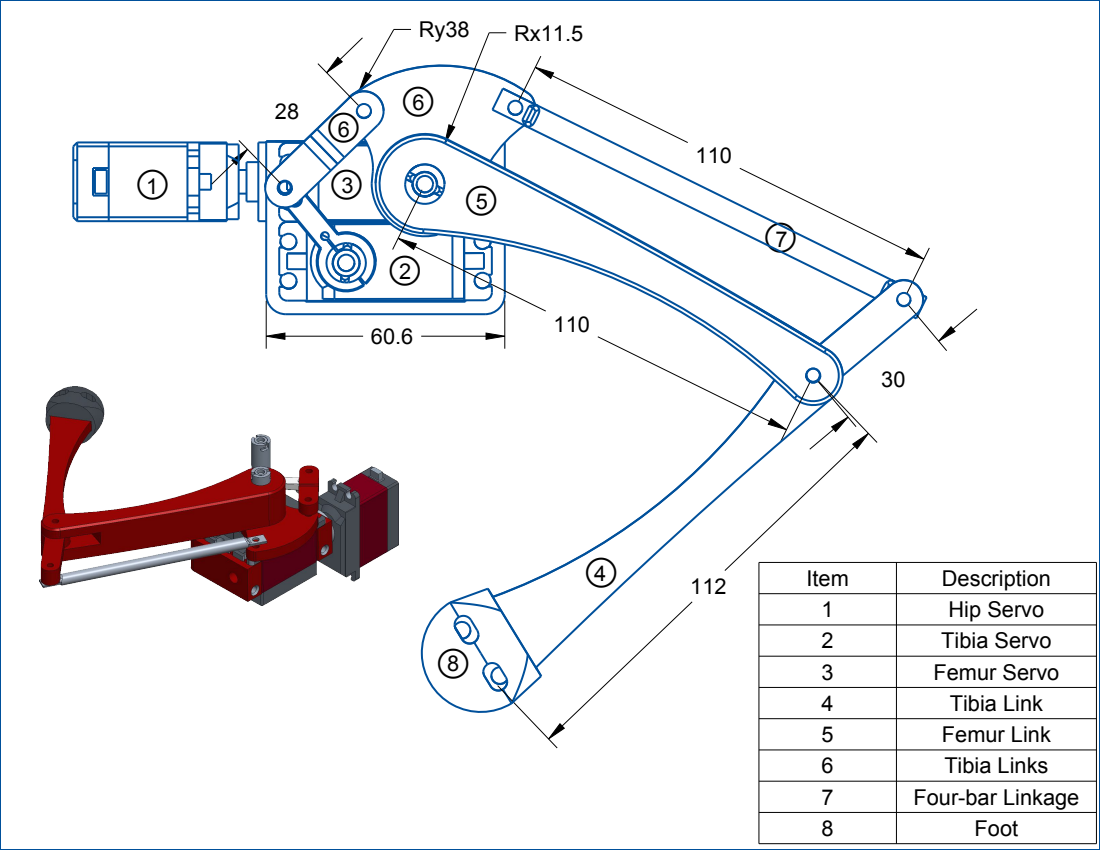
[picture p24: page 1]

Item | Description
1 | Hip Servo
2 | Tibia Servo
3 | Femur Servo
4 | Tibia Link
5 | Femur Link
6 | Tibia Links
7 | Four-bar Linkage
8 | Foot

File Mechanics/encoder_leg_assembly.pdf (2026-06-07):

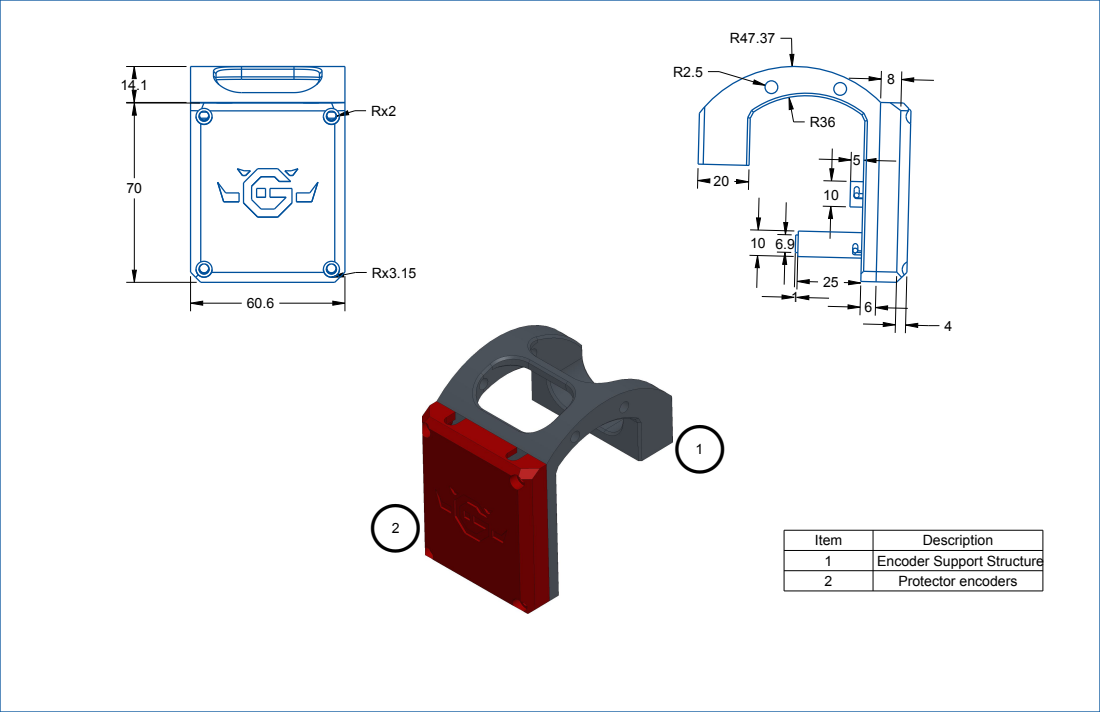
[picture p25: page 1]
Item; Description 1; Encoder Support Structure 2; Protector encoders

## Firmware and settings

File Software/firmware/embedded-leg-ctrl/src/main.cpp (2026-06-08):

#include "config.h"
#include "hardware.h"
#include "mailbox.h"
#include "tasks.h"
#include "utilities.h"

#if Z_FEATURE_PUBLICATION == 1

void setup()
{
  pinMode(LED_PIN, OUTPUT);
  Serial.begin(115200);

  Wire.end();
  Wire1.end();

  Wire.begin(8, 9);
  Wire.setClock(400000); // bus freq

  Wire1.begin(17, 18);
  Wire1.setClock(400000);

  // QUEUES
  Queues::joint_states_queue = xQueueCreate(1, 4 * 3 * sizeof(float));
  Queues::time_stamp_queue = xQueueCreate(1, sizeof(double));
  Queues::imu_data_queue = xQueueCreate(1, sizeof(IMUdata));
  Queues::encoder_data_queue = xQueueCreate(1, 4 * 3 * sizeof(float));

  beginNetwork();

  // indicate network setup done
  digitalWrite(LED_PIN, HIGH);

  // Servos
  Serial.println("SYSTEM: Initializing PCA9685 Servos");
  pwm.begin();
  pwm.setOscillatorFrequency(27000000);
  pwm.setPWMFreq(PCA9685Cfg::freq); // 200Hz from namespace
  delay(10);                        // debouncing

  // IMU
  imu.begin();
  imu.calibrate();
  imu.beginMag();
  imu.calibrateMag();

  // homing to rest
  leg_lf.write(0.7, 0.8, 0.8);
  leg_rf.write(0.7, 0.8, 0.8);
  leg_lh.write(0.7, 0.8, 0.8);
  leg_rh.write(0.7, 0.8, 0.8);
  //---DEBUGGING--- Pos 0
  // leg_lf.write(0.0, 0.0, 0.0);
  // leg_rf.write(0.0, 0.0, 0.0);
  // leg_lh.write(0.0, 0.0, 0.0);
  // leg_rh.write(0.0, 0.0, 0.0);

  // threads declarations
  xTaskCreatePinnedToCore(watchdogTask, "watchdog", 4096, NULL, 1, NULL, 0);
  xTaskCreatePinnedToCore(writeServosTask, "servos", 4096, NULL, 3, NULL, 1);
  xTaskCreatePinnedToCore(readIMUTask, "imu_read", 4096, NULL, 2, NULL, 1);
  xTaskCreatePinnedToCore(readEncodersTask, "encoders_read", 4096, NULL, 2, NULL, 1);
  xTaskCreatePinnedToCore(sendStatusTask, "send_status", 4096, NULL, 2, NULL, 1); // core 1: latency min/avg/max/mdev = 4.512/7.733/22.248/2.542 ms
                                                                                  //  core 0: latency min/avg/max/mdev = 4.872/9.381/62.122/4.254 ms
}

void loop()
{
}
#endif

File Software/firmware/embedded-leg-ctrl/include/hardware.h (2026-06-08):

// HARDWARE INTERFACE HEADER FILE
#ifndef _HARDWARE_H_
#define _HARDWARE_H_

#include "PCA9685.h"
#include "IMUMPU9250.h"

struct Leg
{
  PCA9685Servo haa; // hip abductor adductor
  PCA9685Servo hfe; // hip flexor extensor
  PCA9685Servo kfe; // knee flexor extensor

  Leg(Adafruit_PWMServoDriver *driver, int haa_channel, int hfe_channel, int kfe_channel) // struct constructor
      : haa(driver, haa_channel),
        hfe(driver, hfe_channel),
        kfe(driver, kfe_channel)
  {
  }

  void setLimit(float haa_limit, float hfe_limit, float kfe_limit)
  {
    haa.setLimit(haa_limit);
    hfe.setLimit(hfe_limit);
    kfe.setLimit(kfe_limit);
  }
  void write(float haa_rads, float hfe_rads, float kfe_rads)
  {
    haa.write(haa_rads);
    hfe.write(hfe_rads);
    kfe.write(kfe_rads);
  }
  void writeDegrees(float haa_degs, float hfe_degs, float kfe_degs)
  {
    haa.writeDegrees(haa_degs);
    hfe.writeDegrees(hfe_degs);
    kfe.writeDegrees(kfe_degs);
  }
};

namespace ServoParams
{
  // Channels of PCA board

  static constexpr uint8_t lf_haa_channel = 0;
  static constexpr uint8_t lf_hfe_channel = 1;
  static constexpr uint8_t lf_kfe_channel = 13;
  static constexpr uint8_t rf_haa_channel = 12;
  static constexpr uint8_t rf_hfe_channel = 4;
  static constexpr uint8_t rf_kfe_channel = 5;
  static constexpr uint8_t lh_haa_channel = 6;
  static constexpr uint8_t lh_hfe_channel = 7;
  static constexpr uint8_t lh_kfe_channel = 8;
  static constexpr uint8_t rh_haa_channel = 9;
  static constexpr uint8_t rh_hfe_channel = 10;
  static constexpr uint8_t rh_kfe_channel = 11;
}

extern Adafruit_PWMServoDriver pwm;

extern Leg leg_lf;
extern Leg leg_rf;
extern Leg leg_lh;
extern Leg leg_rh;

extern float joint_states[4][3];

// imu definition
extern IMUMPU9250 imu;

#endif

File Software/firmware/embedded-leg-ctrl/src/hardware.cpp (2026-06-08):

// IMPLEMENTAION OF THE HARDWARE INTERFACE
#include <hardware.h>

Adafruit_PWMServoDriver pwm = Adafruit_PWMServoDriver(0x40, Wire1); // PCA instance

// struct instances
Leg leg_lf(&pwm, ServoParams::lf_haa_channel, ServoParams::lf_hfe_channel, ServoParams::lf_kfe_channel);
Leg leg_rf(&pwm, ServoParams::rf_haa_channel, ServoParams::rf_hfe_channel, ServoParams::rf_kfe_channel);
Leg leg_lh(&pwm, ServoParams::lh_haa_channel, ServoParams::lh_hfe_channel, ServoParams::lh_kfe_channel);
Leg leg_rh(&pwm, ServoParams::rh_haa_channel, ServoParams::rh_hfe_channel, ServoParams::rh_kfe_channel);

float joint_states[4][3] = {{0.0, 0.0, 0.0}, {0.0, 0.0, 0.0}, {0.0, 0.0, 0.0}, {0.0, 0.0, 0.0}};

// imu implementation
IMUMPU9250 imu(0x68, 0x0C);

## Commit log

2026-06-07 Add finals stl
    [base_dog.stl, carcasa_final.stl, hombrera_encoders.stl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]
2026-06-08 added varaible for each motor leg, and loop is always moving servos
2026-06-08 Added namespaces for pwm params and limit functions
2026-06-08 Added libraries for CDR lectures, wifi manager and created library for IMU
2026-06-08 Added function to deserialize JointStates msg. RTOS implementation with queues and tasks for dinamic variables control. Added whatchdog task and sensor lecture tasks. Implemented latency calculations.
2026-06-08 Changed settings of the project to run in a ESP32-S3X
2026-06-08 Implemented a library to read Imu accel gyro and mag. It is sent by zenoh to ros2. The calibrations are done in the setup. Implemented serialization function
2026-06-08 Updated readme to add a servos test and madgwick filter for IMU
2026-06-08 Implemented a pca9685 library wrap for controlling our servos, with its respective map for 180 degrees, and other functions adapted. also corrected deserialize function to not loose data. comented Se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
    [hardware.cpp, hardware.h, main.cpp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]
2026-06-08 Implemented one multiplexor encoders reading and debugging tests in the loop
2026-06-08 Implemented Encoders with multiplexor, tuned connectivity parameters, aded serializaion of jointstates, optimized code and updated readmes. Last modification before presentation
2026-06-08 added meshes
    [base_dog.stl, base_dog_correct.stl, cad_servo20kg_p4_correct.stl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]
2026-06-08 added definitive xmls
    [robot.xml]
2026-06-08 Added collisions and real mass for inertia
    [base_dog.stl, base_dog_correct.stl, cad_servo20kg_p4_correct.stl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]
2026-06-08 correct joint limits
2026-06-08 added encoders meshes
    [base_dog_correct_con_p_trasera.stl, hombro_pierna_correct_encoders.stl, hombro_pierna_correct_r_encoders.stl]
2026-06-23 replaced files, delated src folder
    [base_dog.stl, base_dog_correct.stl, base_dog_correct_con_p_trasera.stl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]
2026-11-08 Added test for each joint
2026-11-11 created workspace with descrioption, harcoded routines, interface for data checking, edited madgwick filter, and other features
2026-11-11 optimized functions such as watchdog, send status, there are now more flags, led colors for each status, calibration saved to nvm
2026-11-11 test for comunication, legs, joint limits. removed the commets with tests in code, now is cleaner
